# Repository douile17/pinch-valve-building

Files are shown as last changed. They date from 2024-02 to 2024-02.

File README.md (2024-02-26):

# Index

Documentation page here ---> https://douile17.github.io/pinch-valve-building/

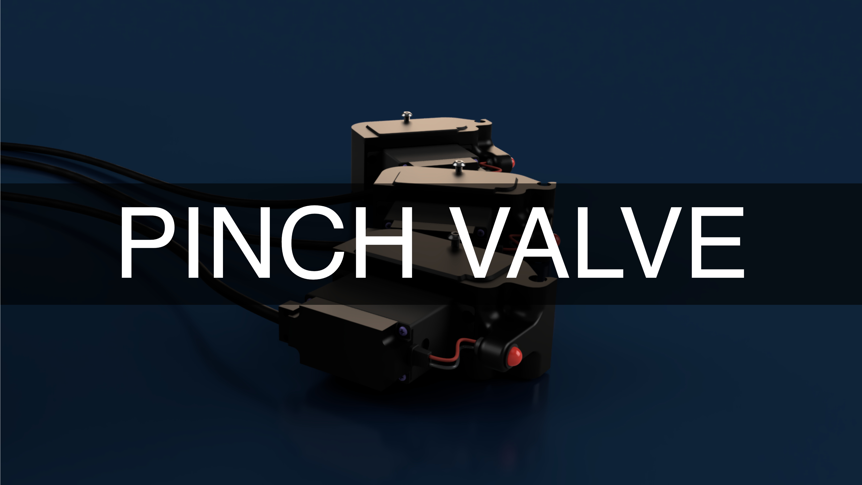
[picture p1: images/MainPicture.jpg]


**Introduction:**

Explore the future of fluid regulation with our Pinch Valve 3D, meticulously crafted to seamlessly integrate with the Multistat. This economical valve, entirely 3D-printed with cost-effective components, provides a high-performance solution tailored to your machine.
This pinch valve is compatible with the following pipes:  [Click here](Parts.yaml#Pipe){Qty: 1} 

**Key Features:**

- **Optimal Compatibility with the Multistat:** Our Pinch Valve 3D seamlessly adapts to the Multistat, ensuring flawless synergy between the valve and the machine.

- **Costs Controlled without Compromise:** Manufactured with budget-friendly components while maintaining reliable performance, this valve delivers quality fluid regulation at an affordable price.

- **Quick and Simple Installation:** The design streamlines the installation process on the Multistat, saving your time and simplifying integration.

- **Almost Nonexistent Wear:** After a year of continuous use without any issues, our Pinch Valve 3D demonstrates exceptional durability with virtually nonexistent wear.

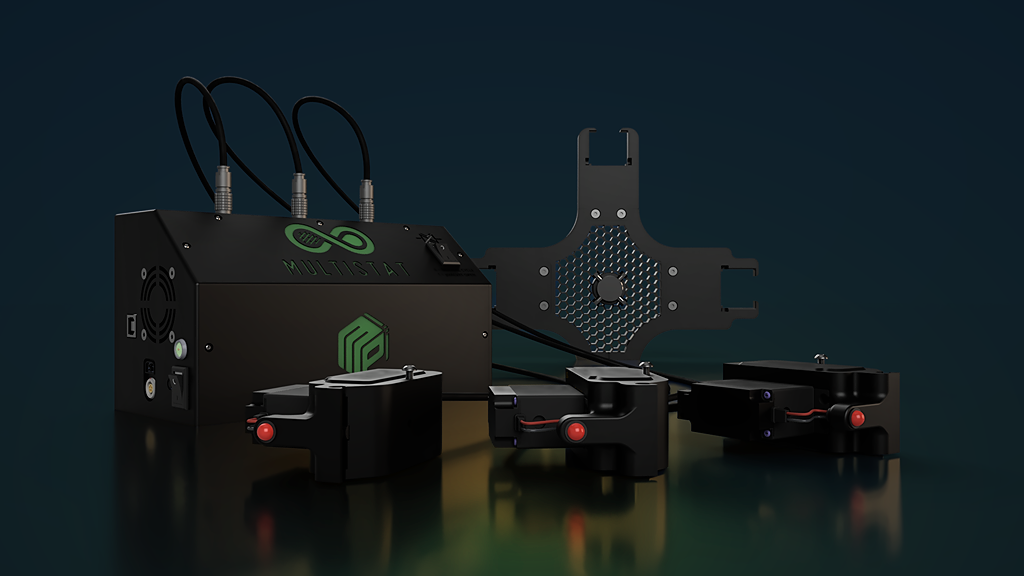
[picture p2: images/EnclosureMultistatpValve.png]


**Choose Proven Reliability:**

Opt for the Pinch Valve 3D with the Multistat and benefit from an economical solution that provides consistent and reliable fluid regulation. Explore this documentation to understand how our technology can enhance the performance of your Multistat without compromising your budget. Get ready for worry-free regulation, where durability and efficiency converge to propel your business to new heights.

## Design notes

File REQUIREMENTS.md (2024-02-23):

# 1-  REQUIREMENTS

## 3D printer used and configuration: {pagestep}

*  [Prusa Mk4](https://www.prusa3d.com/product/original-prusa-mk4-2/)
* [Prusa Mk3s+](https://www.prusa3d.com/fr/produit/imprimante-3d-original-prusa-i3-mk3s-3/)

>? **Help Block** 
>?
>? I'm using the MK4, but if you have an MK3S+, that works just as well. The advantage of the MK4 is that bed leveling is automatic, and the load cell on the nozzle ensures perfect printing without optimal settings.

## Settings: {pagestep}
 
* Plastic: [PETG](https://www.prusa3d.com/fr/produit/prusament-petg-carbon-fiber-black-1kg/)
* Infil: 60%
* Solid layers: 
    * Top: 6
    * Bottom: 5
* Minimum shell thickness: 
    * Top: 0.7mm
    * Bottom: 0.5mm

>! **Caution** 
>!
>! When printing with PETG, it is imperative to use the textured build plate. Attempting to print PETG on a smooth bed may risk damaging the bed when removing the print after printing.

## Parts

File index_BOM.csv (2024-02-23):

Name in documentation | Category | Qty | Full Name | Notes | Supplier 1 | Part No | Link
allen key | tool | 1
bearing | part | 1 | bearing 10mm |  | RS | 618-9884 | https://befr.rs-online.com/web/p/ball-bearings/6189884
cable | part | 1 | Multicore Cable |  | FARNELL | 1204281 | https://uk.farnell.com/lapp-kabel/0034405/cable-liycy-5core-0-25mm-50m/dp/1204281?ost=1204281
Click here | part | 1 | Pipe 0,040" |  | VWR | 228-1702 | https://be.vwr.com/store/catalog/product.jsp?catalog_number=228-1702
heat shrink | part | 1 | RS PRO Heat Shrink Tubing |  | RS | 700-4624 | https://uk.rs-online.com/web/p/heat-shrink-tubing/7004624?searchId=222870df-40eb-45f3-b95a-6bf57d72900d&gb=s
LEMO connector | part | 1 | Lemo FGG.0B.305.CLAD52Z |  | FARNELL | 3817258 | https://be.farnell.com/fr-BE/lemo/fgg-0b-305-clad52z/fiche-s0-5-voies-5mm/dp/3817258?ost=3817258
M2x6 | part | 1 | M2 Pan Head M2x6 |  | RS | 528-693 | https://befr.rs-online.com/web/p/machine-screws/0528693
M3x12 CHC | part | 1 | M3x12 CHC screw black |  | RS | 467-9802 | https://befr.rs-online.com/web/p/socket-screws/4679802
M3x6 | part | 4 | M3x6 Pan Steel Machine Screws DIN 7985Z |  | RS | 560-580 | https://uk.rs-online.com/web/p/machine-screws/0560580?searchId=7490213b-4339-4d40-a498-d6648054c459&gb=s
screw driver | tool | 1
servo motor | part | 1 | Servo Parallax Inc 4 |  | RS | 781-3058 | https://befr.rs-online.com/web/p/servo-motors/7813058
soldering iron | tool | 1
stripping pliers | tool | 1
wire cutter | tool | 1

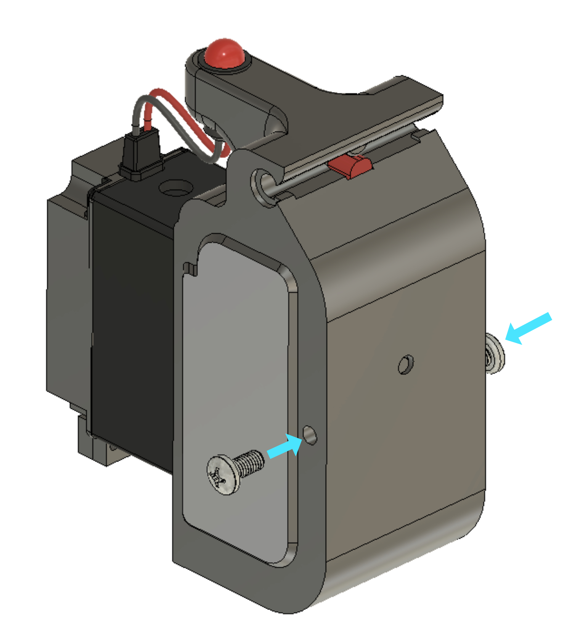
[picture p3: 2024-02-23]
images/parts_assembly/support_screws.jpg

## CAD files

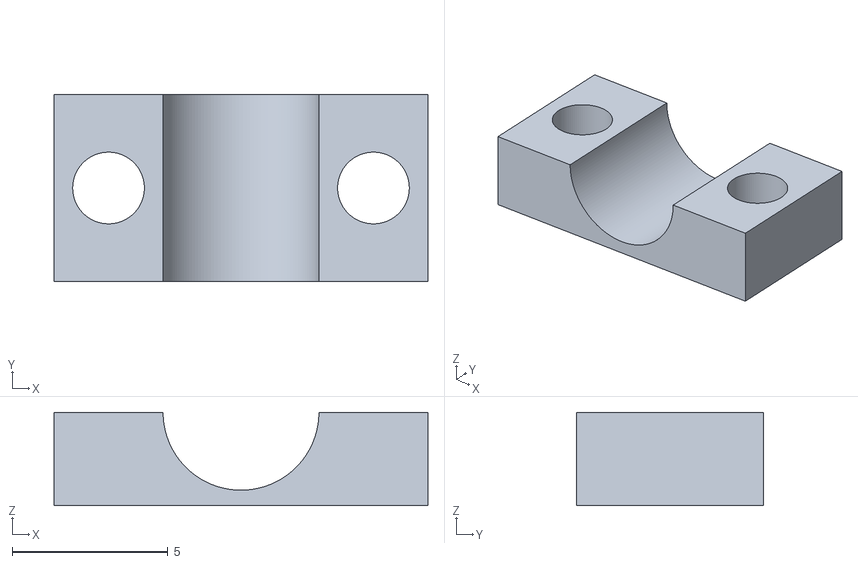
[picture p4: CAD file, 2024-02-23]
3d_models/cable_clamp.stl
12.0 x 6.00 x 3.00

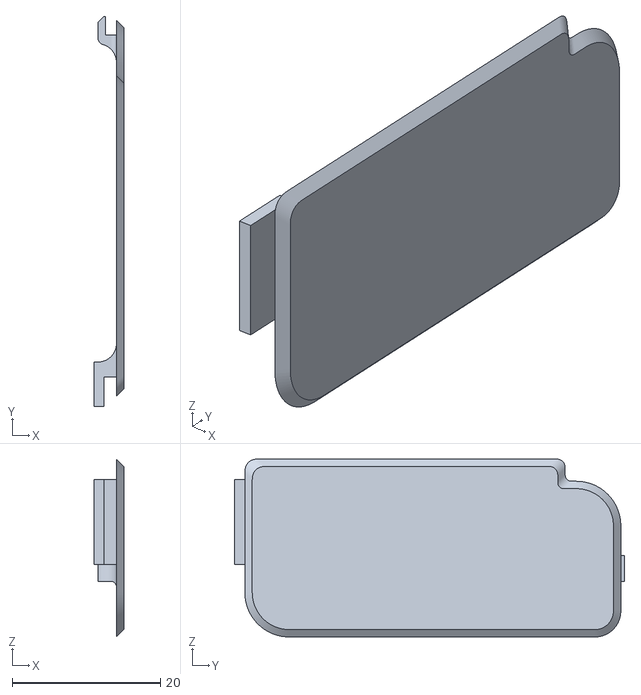
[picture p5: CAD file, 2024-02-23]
3d_models/cams_cover_R.stl
4.00 x 52.6 x 24.0

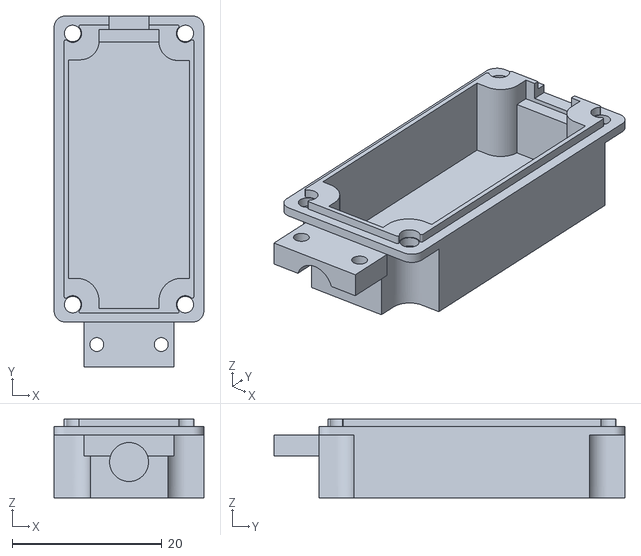
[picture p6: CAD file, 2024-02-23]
3d_models/servo_cap.stl
20.0 x 46.9 x 10.5

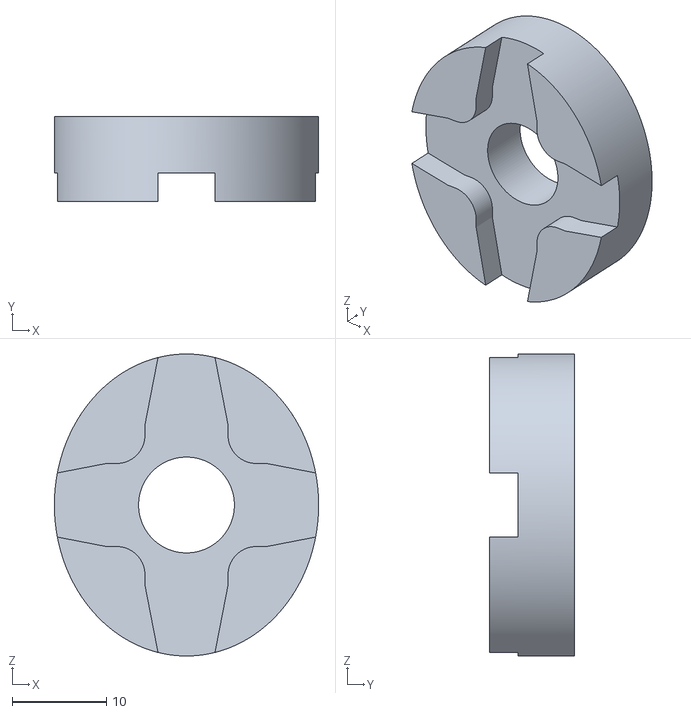
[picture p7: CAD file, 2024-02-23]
3d_models/cam.stl
28.0 x 9.00 x 32.0

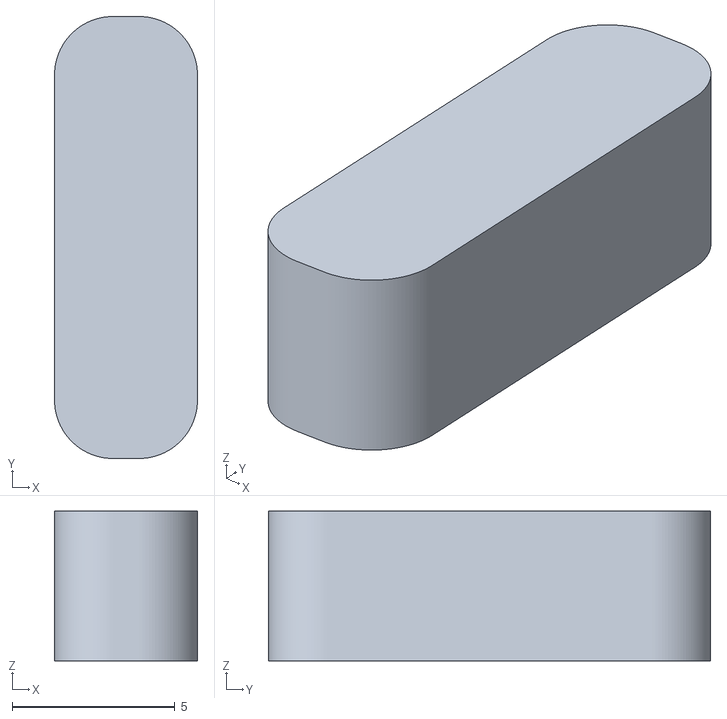
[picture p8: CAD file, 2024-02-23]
3d_models/clamp.stl
4.40 x 13.6 x 4.60

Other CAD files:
3d_models/cams_cover_L.stl

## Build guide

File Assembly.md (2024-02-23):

{{BOM}}

# 2-  Parts Assembly

## Cam & Bearing {pagestep}

* Insert the [bearing](Parts.yaml#Bearing){Qty: 1} into the rotary [cam.stl](3d_models/cam.stl){previewpage} 

<!-- You can drag and drop your images directly here and use this template -->
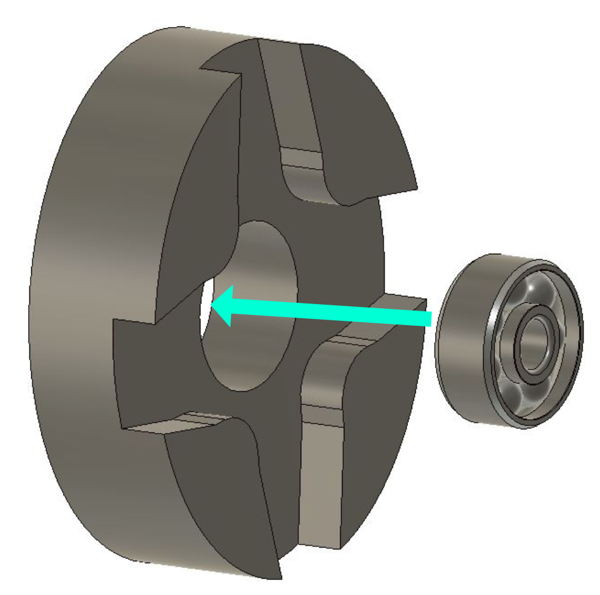
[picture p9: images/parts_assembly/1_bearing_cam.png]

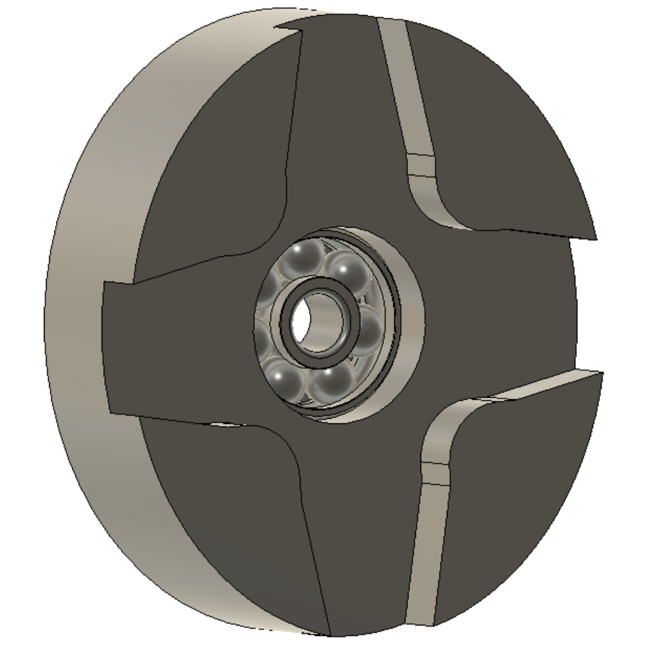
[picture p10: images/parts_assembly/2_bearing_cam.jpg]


## Clamp {pagestep}

* Place the  [clamp.stl](3d_models/clamp.stl){previewpage} into the [main part.stl](3d_models/main_part.stl){previewpage}

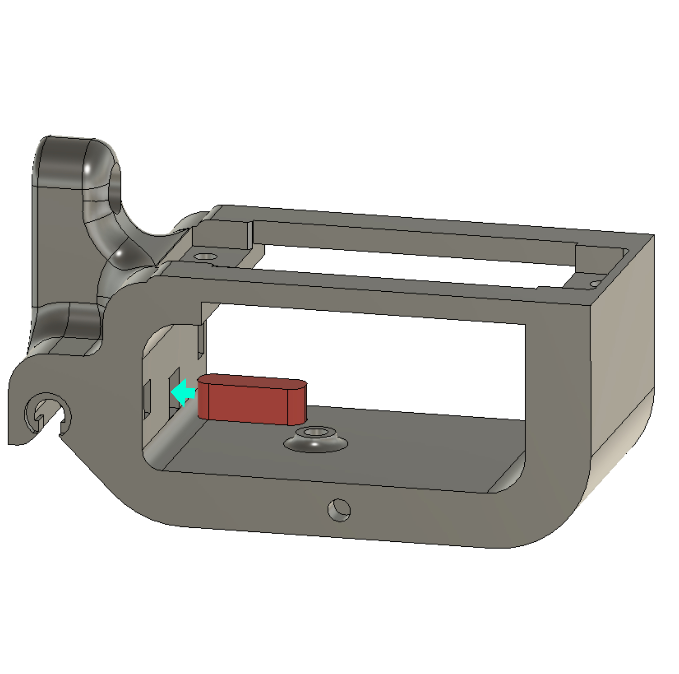
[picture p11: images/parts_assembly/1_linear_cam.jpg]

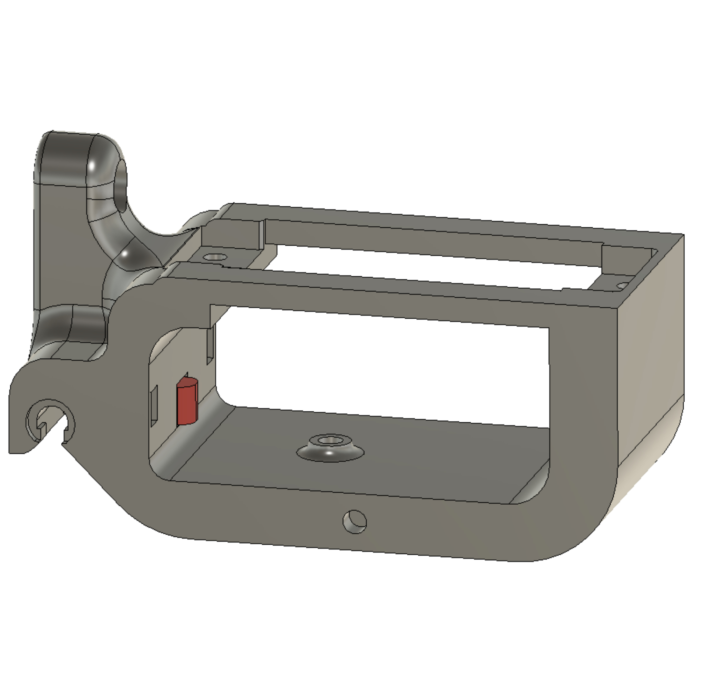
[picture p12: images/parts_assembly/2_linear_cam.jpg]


## Secure Rotary Cam{pagestep}

* Insert the screws [M3x12 CHC](Parts.yaml#M3x12CHC){Qty: 1} socket head cap screw to secure the rotary cam onto the main component with an [allen key]{Qty: 1, Cat: tool} .

>i **Note** 
>i
>i You must screw directly into the plastic.

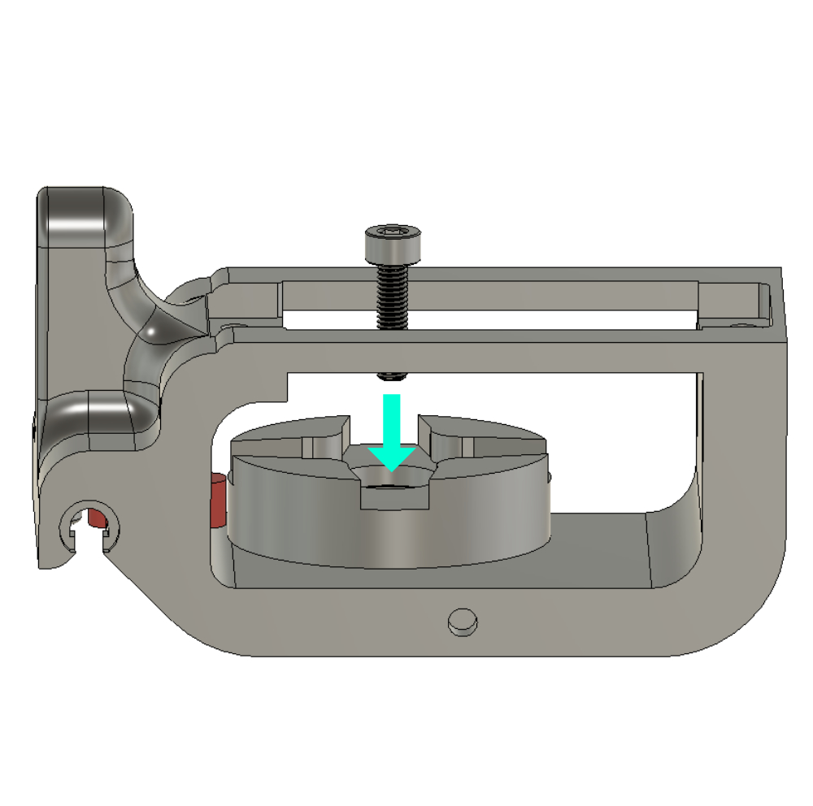
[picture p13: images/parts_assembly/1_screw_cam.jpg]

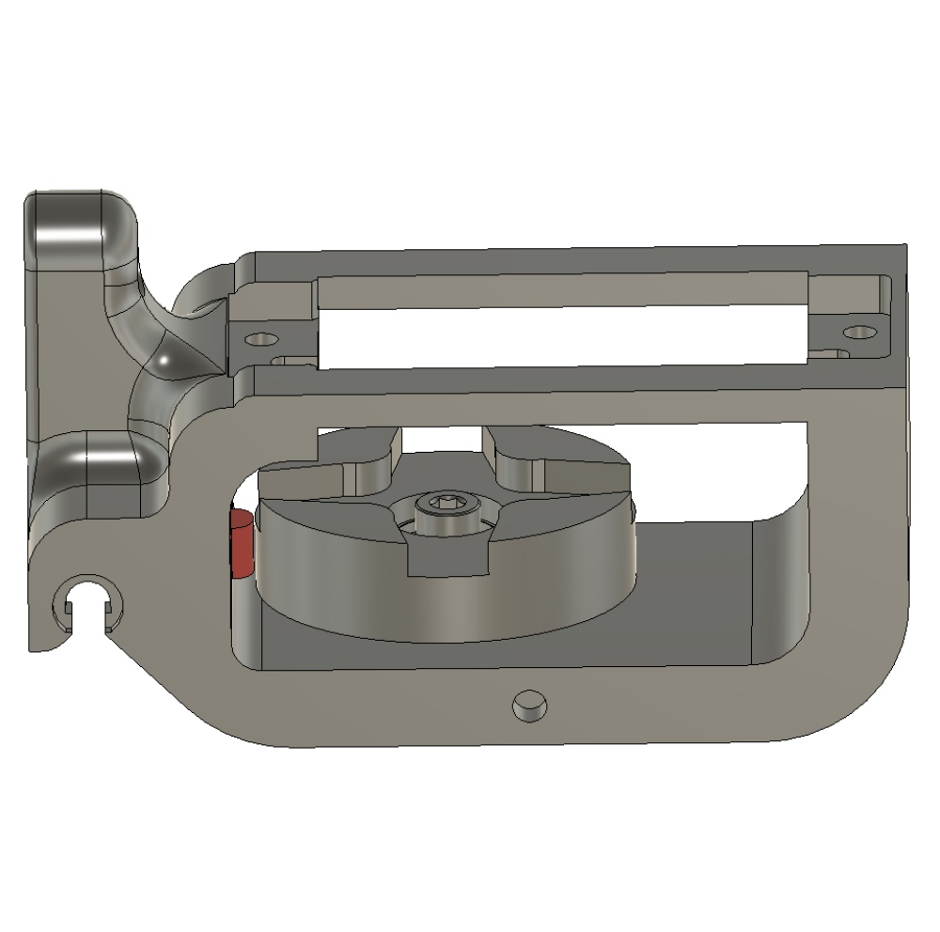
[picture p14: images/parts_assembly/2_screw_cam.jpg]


##Servo Motor{pagestep}
* Take the [servo motor](Parts.yaml#Servo){Qty: 1}  and reduce the size of the blades with a [wire cutter]{Qty: 1, Cat: tool} to ensure a proper fit with the rotary cam coupling.

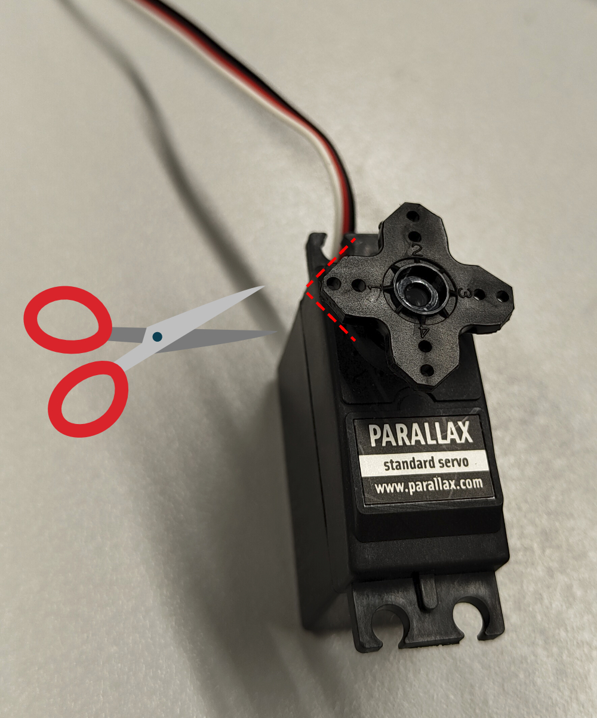
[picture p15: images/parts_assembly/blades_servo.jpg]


## Secure servo motor{pagestep}
* Screw the servo motor onto the main part using [M3x6](Parts.yaml#M3x6){Qty: 4} screws x4 and  [allen key]{Qty: 1, Cat: tool} or  [screw driver]{Qty: 1, Cat: tool} depending on the type of screws used.
>i **Note** 
>i
>i You must screw directly into the plastic

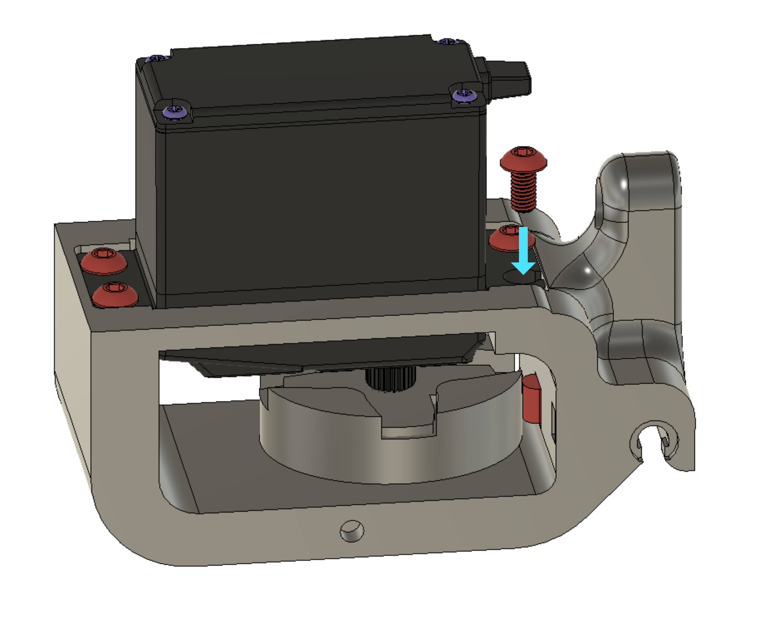
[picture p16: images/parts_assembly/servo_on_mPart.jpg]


* Remove the four screws from the servo motor casing.

>! **Caution** 
>!
>! Do not discard the four screws as we will reuse them in the next step.

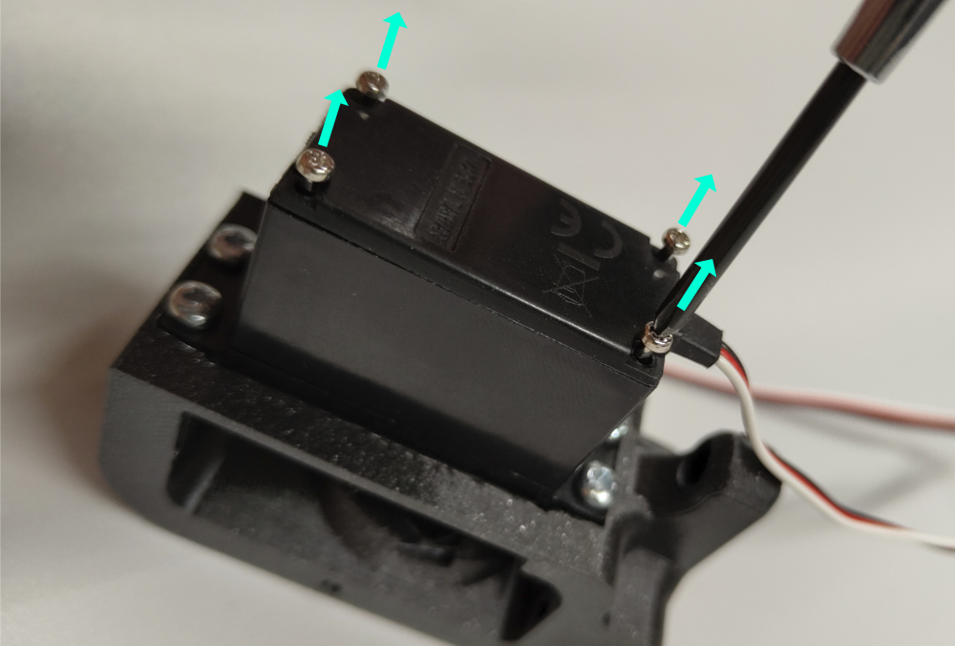
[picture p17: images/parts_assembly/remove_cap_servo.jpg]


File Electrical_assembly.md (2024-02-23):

{{BOM}}

# 3- Electrical assembly

## Led {pagestep}

* Cut the servo motor wires with a [wire cutter]{Qty: 1, Cat: tool} and retrieve the cable gland for further steps, then insert the LED into its designated slot.
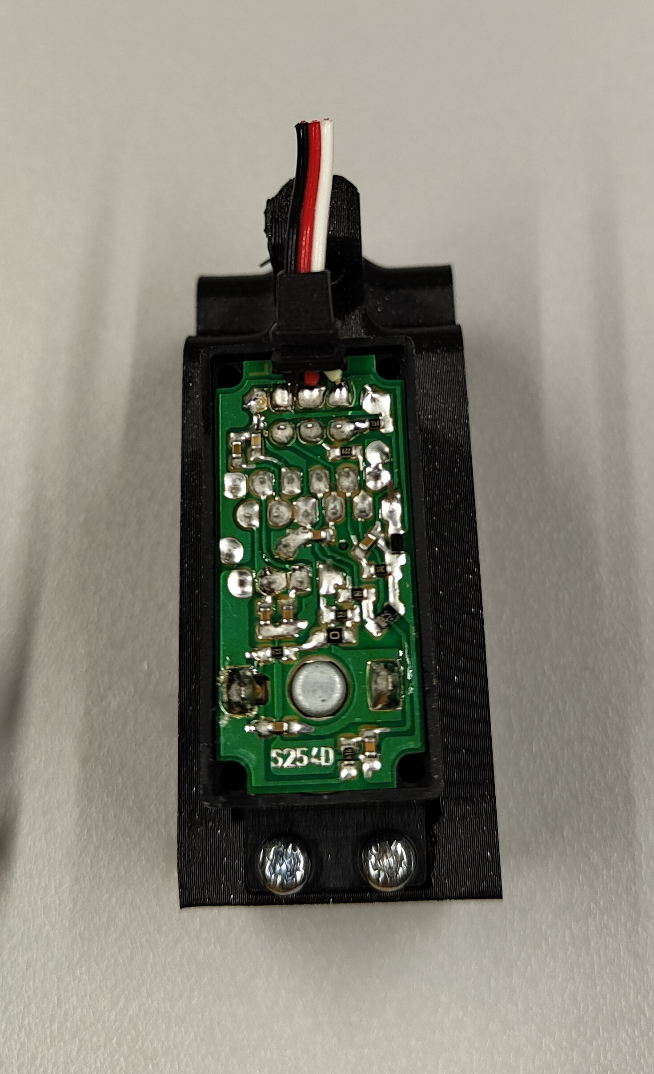
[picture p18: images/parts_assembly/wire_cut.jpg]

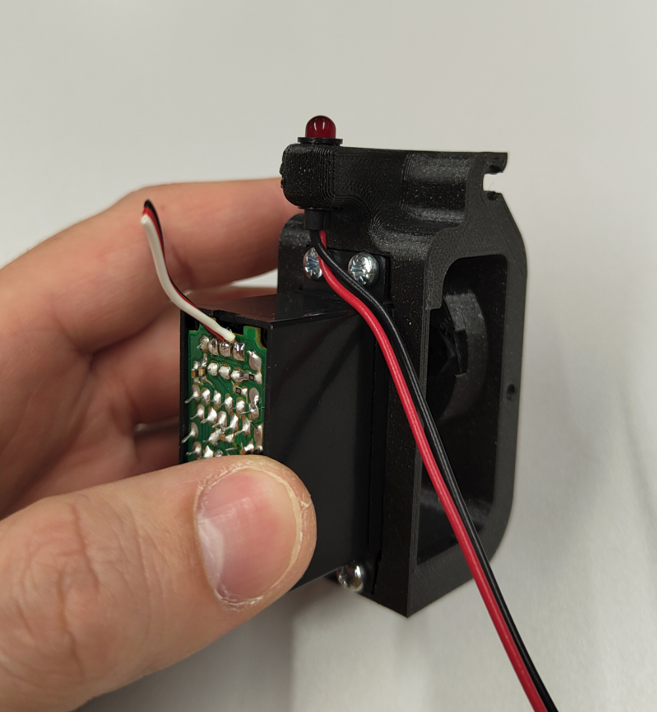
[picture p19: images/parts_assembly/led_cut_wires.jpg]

<!-- You can drag and drop your images directly here and use this template -->

## Preparation of the servo cap {pagestep}

* Insert the [cable](Parts.yaml#cable){Qty: 1} into the hole of the [servo cap.stl](3d_models/servo_cap.stl){previewpage}, and pull it sufficiently to strip it. Strip the cable 2.5 cm with a [stripping pliers]{Qty: 1, Cat: tool}. 

>! **Caution** 
>!
>!  Careful not to cut the strands inside

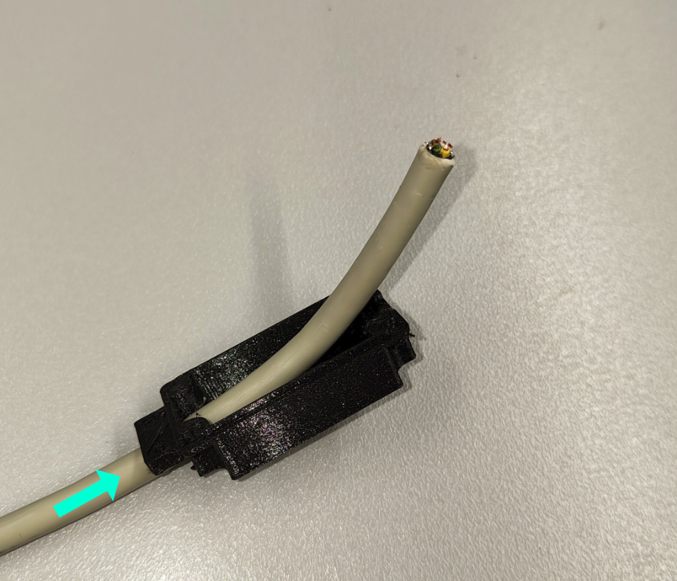
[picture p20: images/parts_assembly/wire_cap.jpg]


## Solder onto the PCB {pagestep}

* Cut the LED cables so they reach the bottom of the PCB compartment of the servo motor.
* Strip and solder the wires as shown in the photo with a [soldering iron]{Qty: 1, Cat: tool} to replace the original wires: Black to Grey, Red to Brown, and White to White.
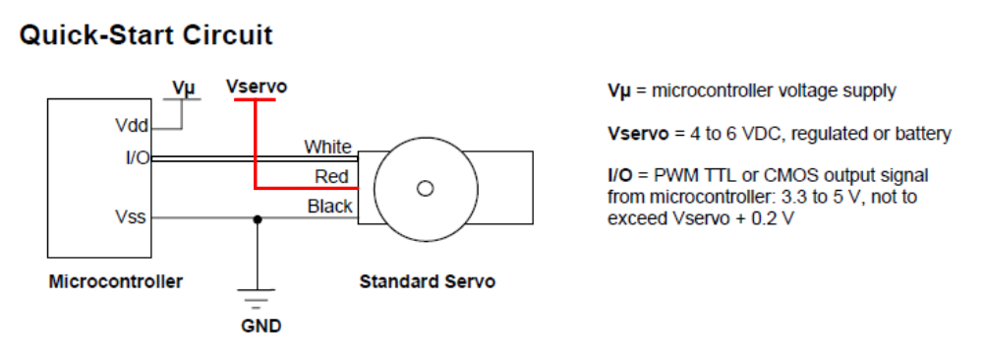
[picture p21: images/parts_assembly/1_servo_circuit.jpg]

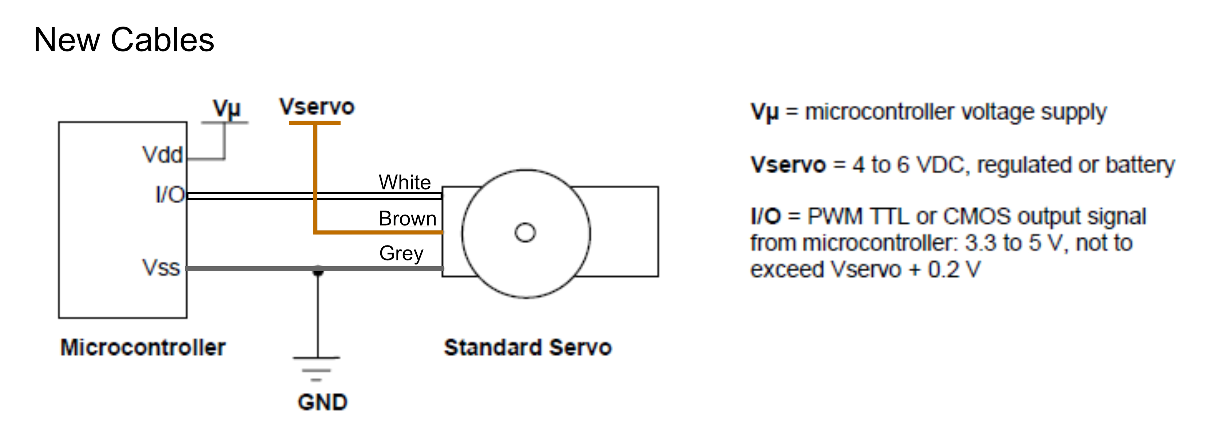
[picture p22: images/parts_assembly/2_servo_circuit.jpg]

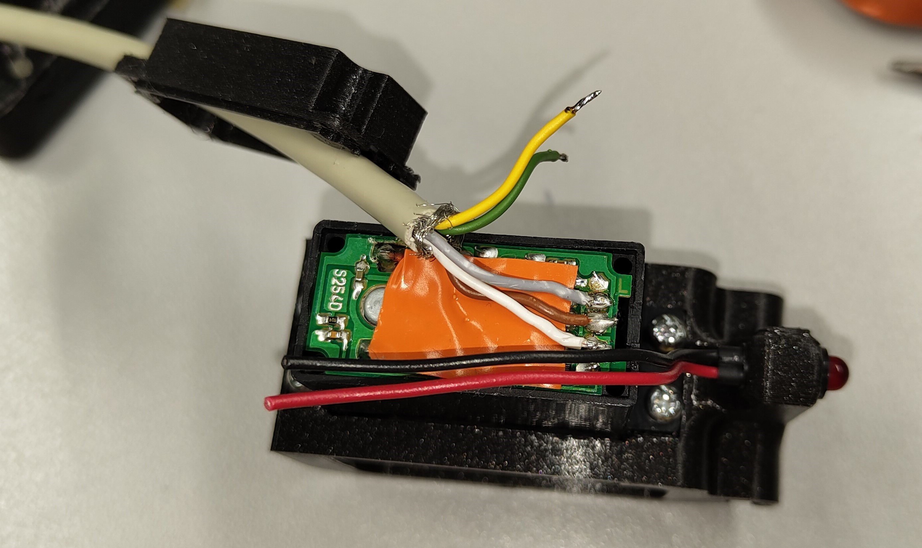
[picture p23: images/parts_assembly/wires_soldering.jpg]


## Led wires {pagestep}

* Ensure that you have reattached the cable gland from the servo motor wires onto the LED cables. Solder the red LED cable to the yellow cable, then solder the black cable to the green one, securing the connections with [heat shrink](Parts.yaml#Heat_Shrink){Qty: 1} tubing.

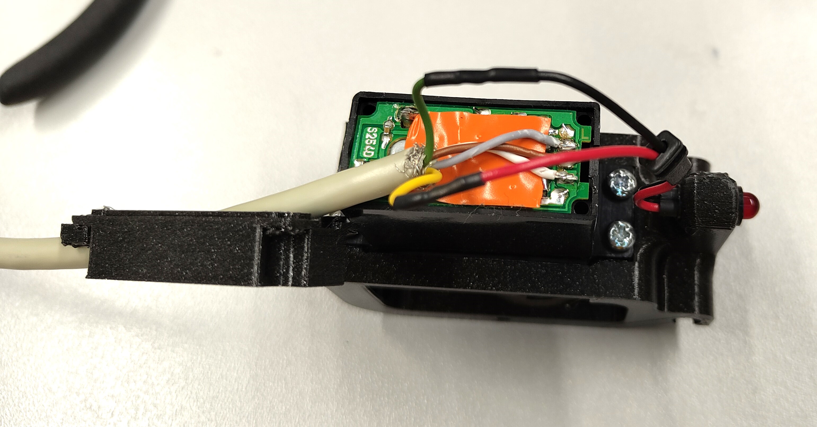
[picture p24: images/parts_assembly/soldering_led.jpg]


* Secure the servo cap onto the servo motor using the four screws previously retained.

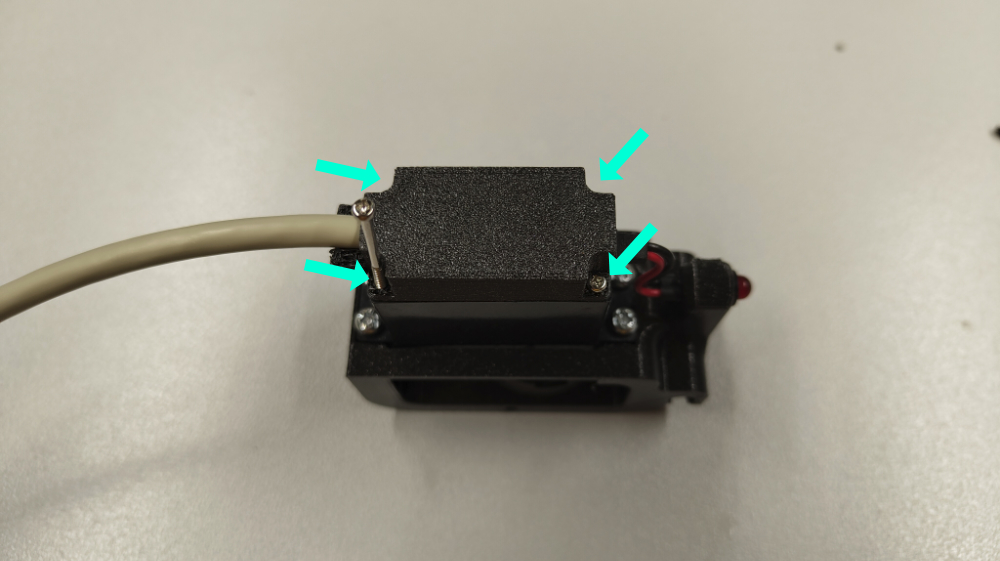
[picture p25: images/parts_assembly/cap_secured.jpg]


* Screw the [cable clamp.stl](3d_models/cable_clamp.stl){previewpage} in place using the two [M2x6](Parts.yaml#M2x6){Qty: 1} screws. 

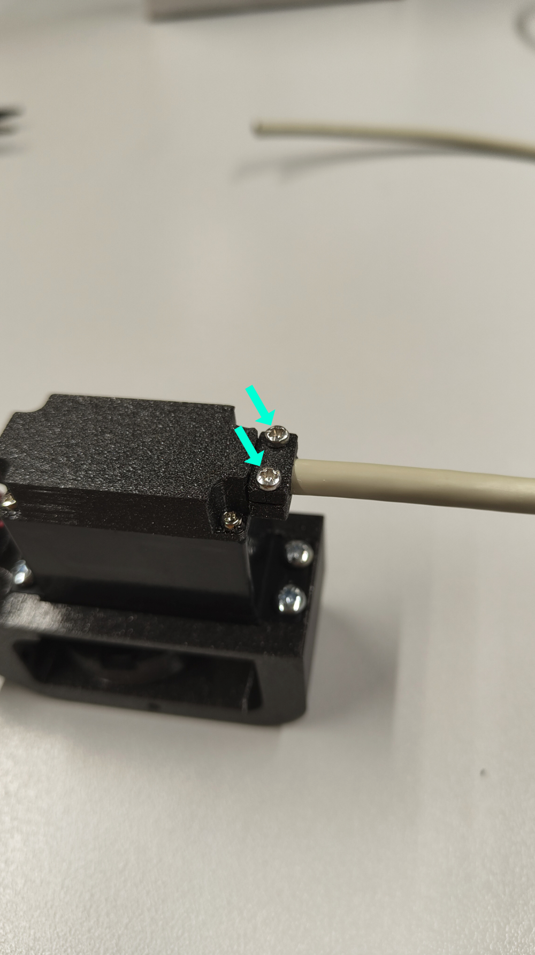
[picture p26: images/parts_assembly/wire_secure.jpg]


## Solder the connector{pagestep}

* Strip the end of the 5-strand cable to approximately 1cm.
* Solder the strands of the cable onto the pins of the [LEMO connector](Parts.yaml#Lemo){Qty: 1} following the diagram.

>!! **Warning** 
>!!
>!! Don't forget to insert all the parts of the lemo connector on the cable before soldering the wires. 

* Then tighten the connector's clamping screw to close it.

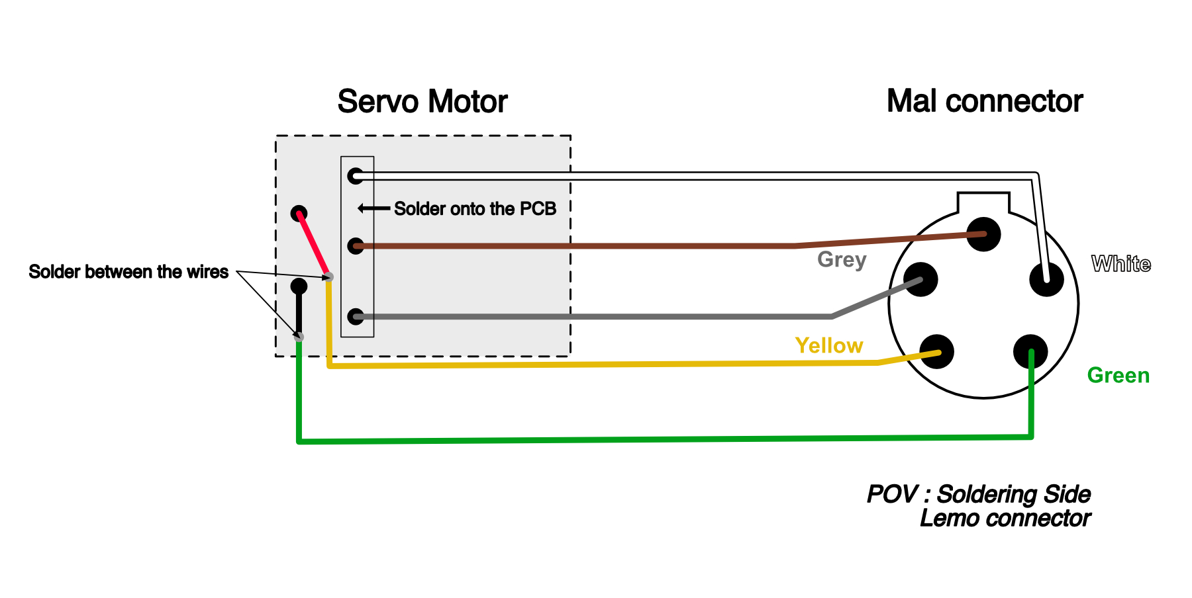
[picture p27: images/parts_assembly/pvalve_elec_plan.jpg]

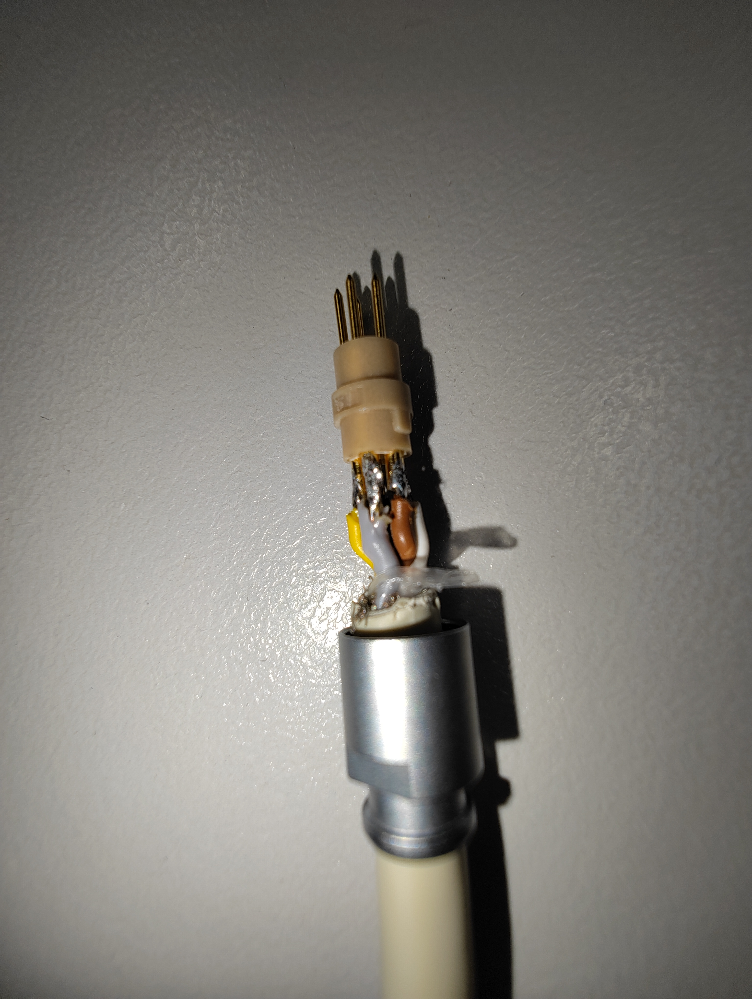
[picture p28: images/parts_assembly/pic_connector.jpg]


## Tadam !!{pagestep}

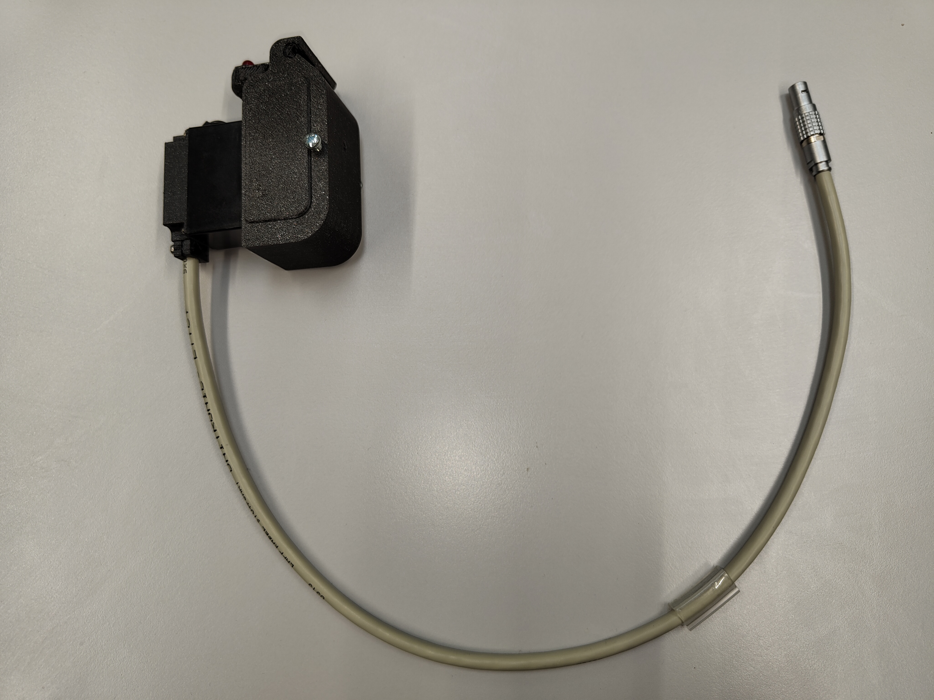
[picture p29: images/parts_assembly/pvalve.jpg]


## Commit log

2024-02-23 Deploying to main from @ 97b8204c15add8b2e5422e029c51e5c12d497029 🚀
    [index_BOM.csv]
2024-02-26 Deploying to main from @ ee8b0cdb5207a09bc5b2939e56d2cd839d48859e 🚀
2024-02-26 Deploying to main from @ 6605c0952d1a8463f3822dcbb40f02d3fb178239 🚀
2024-02-26 Deploying to main from @ 07932568a51173e25c48336e4eb75cc50642dfba 🚀
